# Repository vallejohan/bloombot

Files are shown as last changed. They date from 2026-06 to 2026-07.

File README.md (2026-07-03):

<p align="center">
  
</p>

<h1 align="center">BloomBot</h1>

<p align="center">
  <strong>Your friendly garden irrigation controller.</strong><br>
  Using a Raspberry Pi, with home assistant integration.
</p>

<p align="center">
  <a href="https://github.com/vallejohan/bloombot/actions/workflows/ci.yml">
    
  </a>
  
  <a href="https://github.com/vallejohan/bloombot/blob/main/LICENSE">
    
  </a>
  <a href="https://github.com/vallejohan/bloombot/releases">
    
  </a>
</p>

---

## What is BloomBot?
A lightweight garden and greenhouse irrigation controller running on a **Raspberry Pi Zero W** (or any other Raspberry Pi) to control a 5V relay board. It integrates with **Home Assistant** over **MQTT** using automatic discovery, and supports both scheduled watering (by time-of-day and duration) and manual overrides.

## Features

- **Multi-Channel Relay Control:** Toggle individual water valves/relays on physical GPIO pins.
- **Humidity & temperature measurement:** Measure the humidity and temperature in the garden/greenhouse using an appropriate sensor (such as DHT22 or a DHT11).
- **Home Assistant Auto-Discovery:** No manual YAML configuration required in Home Assistant. Switches, schedule toggles, start times, and watering durations register automatically.
- **Persistent Schedules:** Schedules are stored locally in `schedules.json` so that they survive Raspberry Pi reboots or power cycles.
- **Flexible Timing:** Set the start time (HH:MM:SS) and duration (1 to 10 minutes) for each relay.
- **Safety Auto-Shutoff:** If the scheduler triggers a relay, it automatically shuts off after the configured duration. If a manual OFF override is received during watering, the timer is immediately cancelled.
- **GPIO Fallback & Mocking:** Automatically detects the physical `gpiozero` library. If run on a non-Pi machine (like Windows/Mac for testing), it runs in **Mock mode** allowing you to test Home Assistant communications.

---

## Limitations & Considerations

Before starting there are some limitations with this project that are good to consider: 

- **WiFi Range Outdoors:** The onboard PCB antenna of the Raspberry Pi Zero W has limited range, which is further reduced when placed inside an enclosure. If the Pi is far from your router, you may experience intermittent MQTT disconnections.
   * *Tip:* Consider planning where the hardware should be placed and if any additional WiFi range extenders are needed.
- **Power Consumption:** Unlike low-power microcontrollers (such as the ESP32) which can enter deep-sleep mode and draw microamps, a Raspberry Pi Zero W consumes quite substantially more power.
  * *Tip:* Running BloomBot purely on batteries is doable, but much less efficient compared to for example an ESP32 device. One option could be to use a larger solar panel setup (e.g., 10W+ solar panel, with a larger 12V LiFePO4 battery, and a step-down converter). A mains-powered supply is highly recommended, if possible.
- **No Native Analog Inputs:** The Raspberry Pi lacks analog-to-digital converters (ADC), in case that you'd like to add analog devices. 
   * *Tip:* If you plan to expand the hardware to read analog soil moisture sensors, or utilize other sensors, you will need to add an external ADC device.

> [!NOTE]
> **Design Philosophy & Hardware Selection**
> 
> This project was originally planned around an ESP32 microcontroller. While an ESP32 would be more optimal on several fronts, such as low power consumption, native ADC support, and support for wireless protocols like Zigbee or Thread, a Raspberry Pi was chosen for a few key reasons:
> - **Power & Proximity:** The greenhouse is close to the main house with a direct power line, which minimizes power consumption constraints.
> - **Extensibility & Easy Updates:** Running a full Linux environment allows for trivial Over-the-Air (OTA) updates and leaves the door open to run other companion services on the same device in the future. That being said, there are also options for OTA updates on ESP32 devices as well.
> - **Hardware Reuse:** It was a good opportunity to put a spare Raspberry Pi board I had lying around to good use.

## System Architecture

BloomBot uses a modular architecture to bridge physical hardware with Home Assistant over an MQTT interface. The main components are detailed below, followed by a system diagram showing how they connect.

1. **BloomBot Core (Raspberry Pi):** A Python application running as a system service. It reads ambient temperature and humidity sensors (via a Linux kernel overlay driver) and manages GPIO outputs to trigger relays.
2. **Local Scheduler & Persistence:** The scheduler runs directly on the Pi and relies on a local JSON file (`schedules.json`) for persistence, ensuring that schedules persist and trigger even during network outages.
3. **MQTT Discovery Layer:** On startup, the script registers all switches, sensors, numbers, and system status configuration topics to the Home Assistant MQTT broker automatically.
4. **Home Assistant Control:** A custom companion frontend card (`bloombot-card`) displays status information and allows the user to easily configure watering schedules, durations, and trigger manual overrides.

```mermaid
graph TD
    %% Styling Definitions
    classDef haStyle fill:#03a9f4,stroke:#0288d1,stroke-width:2px,color:#fff;
    classDef mqttStyle fill:#009688,stroke:#00796b,stroke-width:2px,color:#fff;
    classDef rpiStyle fill:#c2185b,stroke:#880e4f,stroke-width:2px,color:#fff;
    classDef hwStyle fill:#4caf50,stroke:#388e3c,stroke-width:2px,color:#fff;
    classDef userStyle fill:#ff9800,stroke:#f57c00,stroke-width:2px,color:#fff;

    %% Nodes
    subgraph HA ["Home Assistant"]
        Card["BloomBot Lovelace Card"]:::haStyle
        HASwitches["Entities (Switches, Sensors, Inputs)"]:::haStyle
    end

    subgraph Broker ["MQTT Broker"]
        MQTT["Mosquitto / MQTT Broker"]:::mqttStyle
    end

    subgraph Pi ["Raspberry Pi Zero W"]
        Core["BloomBot App (main.py)"]:::rpiStyle
        Sched["Scheduler & Persistence (schedules.json)"]:::rpiStyle
        GPIO["GPIO Manager (gpio_manager.py)"]:::rpiStyle
        DHT["DHT Sensor Module (dht_sensor.py)"]:::rpiStyle
    end

    subgraph HW ["Physical Hardware"]
        DHTSensor["DHT22 Sensor"]:::hwStyle
        Relays["8-Channel Relay Board"]:::hwStyle
        Valves["Water Valves / Pumps"]:::hwStyle
    end

    %% Connections
    User["User Interface / App"]:::userStyle --> Card
    Card <-->|Control & Status| HASwitches
    HASwitches <-->|MQTT Pub/Sub| MQTT
    MQTT <-->|Discovery & Commands| Core
    Core <-->|Saves/Reads Schedules| Sched
    Core -->|Triggers Relays| GPIO
    GPIO -->|GPIO Signals| Relays
    Relays -->|Power Control| Valves
    DHTSensor -->|Sensor Data| DHT
    DHT -->|Readings| Core
```

---

## Hardware Setup

To build the BloomBot controller, you will need the hardware components listed in the Bill of Materials section below. The setup is not restricted to the specific models listed, you can choose various components and scale the number of relays (valves) as needed to fit your garden zones.

### Bill of Materials (BOM)

| Component | Description | Quantity | Example | Notes |
| :--- | :--- | :---: | :--- | :--- |
| **Raspberry Pi** | Raspberry Pi Zero W (or Zero 2 W, RPi 3/4/5) with SD Card | 1 | Raspberry Pi Zero 2 W | Any model with a 40-pin GPIO header will work. |
| **Relay Board** | 5V or 3.3V active-low relay module (1 to 8 channels) | 1 | Elegoo 8-Channel Relay Module | Configure the pins in [config.py](src/config.py) based on your board. |
| **DHT22 / DHT11** | Temperature and humidity sensor | 1 | DHT22 (AM2302) | Optional. Used for monitoring climate; can be disabled in configuration. |
| **Water Valves / Pumps** | 12V solenoid valves (or 24V AC valves / 5V DC pumps) | 1 - 8 | Generic 12V Solenoid Valve | Match the quantity to your garden zones and ensure matching power supply. |
| **Power Supplies** | 12V switching PSU & step-down DC-DC converters | 1 - 2 | Meanwell switching 12V PSU & LM2596 Buck Converter | Separate power supply for relay coils is recommended to isolate noise. |
| **Enclosure** | 3D-printable enclosure | 1 | Custom 3D-printed case | Optional. Helps protect components outdoors (see [Enclosure box](#enclosure-box)). |
| **Misc** | Jumper wires, terminal blocks, mounting hardware | - | Dupont jumper wires, Wago 221 connectors | For connecting and mounting the hardware. |

### Wiring

The wiring schematic image below shows how the hardware components can be wired together. Some good points to take into consideration when setting up this system:

- **Active-Low vs. Active-High:** Most common 8-channel relay boards are *Active-Low* (relays switch ON when the control pin is pulled to GND). This is configured via `ACTIVE_LOW = True` in [config.py](src/config.py).
- **Isolating power to relay and Rpi:** To isolate the Raspberry Pi from relay noise and ensure the 5V relay coils have sufficient power, the usage of two 5V DC-DC converters is recommended (as shown in the schematic). However, using a single 5V DC-DC converter is fully functional as well.

<picture>
  BloomBot wiring schematic
</picture>

### Enclosure box

There is an enclosure box that can be 3d-printed to fit the hardware components. The box has holdings for the Raspberry Pi, relay board, and DHT22 sensor, as well as hole for input power and water valve cables. STL files (and 3mf file) can be found in the [assets/3d-models](assets/3d-models) directory.

---

## Installation & Setup on Raspberry Pi

### 1. Install System Dependencies

Open a terminal on your Raspberry Pi and ensure all required system utilities and build tools are installed:

```bash
sudo apt update
sudo apt install -y python3 python3-pip python3-venv python3-gpiozero swig liblgpio-dev python3-dev build-essential
```

> [!NOTE]
> * **Relay Control:** On modern Debian/Ubuntu environments (such as RPi OS Bookworm), legacy GPIO interfaces are deprecated. To control pins correctly, the application compiles `lgpio` in the virtual environment via the modern `/dev/gpiochip*` API, requiring the compilation dependencies (`swig`, `liblgpio-dev`, `python3-dev`, `build-essential`).

### 2. Clone and Prepare the Script

First, install **uv** if it isn't already installed:

```bash
curl -LsSf https://astral.sh/uv/install.sh | sh
```

> [!TIP]
> After the installer completes, you may need to restart your terminal session or run `source $HOME/.local/bin/env` (for bash/zsh) to add `uv` to your `PATH` variable.

Navigate to your workspace directory and synchronize the dependencies to set up a virtual environment:

```bash
cd /path/to/your/workspace/bloombot
uv sync
```

### 3. Enable Linux Kernel DHT Overlay (Required for DHT22 Sensor)

Python-based user-space bit-banging is highly sensitive to CPU scheduling jitter (especially on single-core devices like the Raspberry Pi Zero W). To achieve stable readings, this application relies on the built-in **Linux Kernel Driver**. The kernel handles timing-sensitive pulse measurements asynchronously via hardware interrupts.

To enable the kernel driver:

1. Open the Raspberry Pi firmware configuration file:
   ```bash
   sudo nano /boot/firmware/config.txt
   ```
2. Scroll to the bottom of the file and add the following lines (under the `[all]` block if present):
   ```text
   [all]
   dtoverlay=dht11,dht22,gpiopin=4
   ```
3. Save the file and reboot your Raspberry Pi:
   ```bash
   sudo reboot
   ```

### 4. Configuration

To configure BloomBot, you can copy the `.env.example` template to `.env` and adjust the variables to fit your network and system:

```bash
cp .env.example .env
```

Open `.env` and set the parameters:
- `MQTT_HOST`: Set your Home Assistant broker IP (defaults to `homeassistant.local`).
- `MQTT_PORT`: Port of the broker (defaults to `1883`).
- `MQTT_USERNAME` / `MQTT_PASSWORD`: MQTT broker login credentials if enabled.
- `MQTT_CLIENT_ID`: The client ID for the MQTT connection (defaults to `rpi_relay_controller`).
- `PERSISTENCE_FILE`: File name to save schedules (defaults to `schedules.json`).
- `DHT_PIN`: BCM pin number connected to the DHT sensor (defaults to `4`).
- `DHT_INTERVAL`: Sensor reading and publishing frequency in seconds (defaults to `60`).

*Note: For properties like `ACTIVE_LOW` and `RELAY_PINS`, you can modify their default values directly in [config.py](src/config.py).*

---

## Running the Daemon

### Running Manually (Testing/Development)

You can run the daemon manually to verify the MQTT broker connection and check the terminal log outputs:

```bash
uv run python src/main.py
```

### Running as a Persistent System Service (`systemd`)

To run the daemon automatically when the Pi boots and ensure it restarts on crashes:

1. Create a systemd service file:
   ```bash
   sudo nano /etc/systemd/system/bloombot.service
   ```

2. Paste the following configuration:
   ```ini
   [Unit]
   Description=BloomBot Irrigation Controller Daemon
   After=network.target mqtt.service

   [Service]
   Type=simple
   User=pi
   WorkingDirectory=/home/pi/bloombot
   ExecStart=/home/pi/bloombot/.venv/bin/python src/main.py
   Restart=always
   RestartSec=5

   [Install]
   WantedBy=multi-user.target
   ```

   > [!IMPORTANT]
   > Replace `User=pi`, `/home/pi/` and paths in the service file above with the actual username and directory path of your Raspberry Pi user if your username is not `pi` (modern Raspberry Pi OS installations require a custom username).

   *(Note: The daemon will automatically load the configuration variables from the `.env` file located in the configured `WorkingDirectory`.)*

3. Enable and start the service:
   ```bash
   sudo systemctl daemon-reload
   sudo systemctl enable bloombot.service
   sudo systemctl start bloombot.service
   ```

4. View service logs to monitor execution:
   ```bash
   sudo journalctl -u bloombot.service -f
   ```

---

## Testing in Mock Mode (Without a Raspberry Pi)

If you are developing or testing on a laptop/desktop computer (e.g. Windows/Mac):

1. Synchronize the environment:
   ```bash
   uv sync
   ```
2. Run the application:
   ```bash
   uv run python src/main.py
   ```
3. The daemon will print `[GPIO-MOCK]` lines showing what the physical pins *would* be doing when you toggle switches in Home Assistant.
4. Use **MQTT Explorer** or the Home Assistant developer tools to verify that entities publish their states and commands are received correctly.

---

## Home Assistant Dashboard Setup

This project includes a Lovelace card designed to control scheduled and manual irrigation valves with configuration dialogs.

<p align="center">
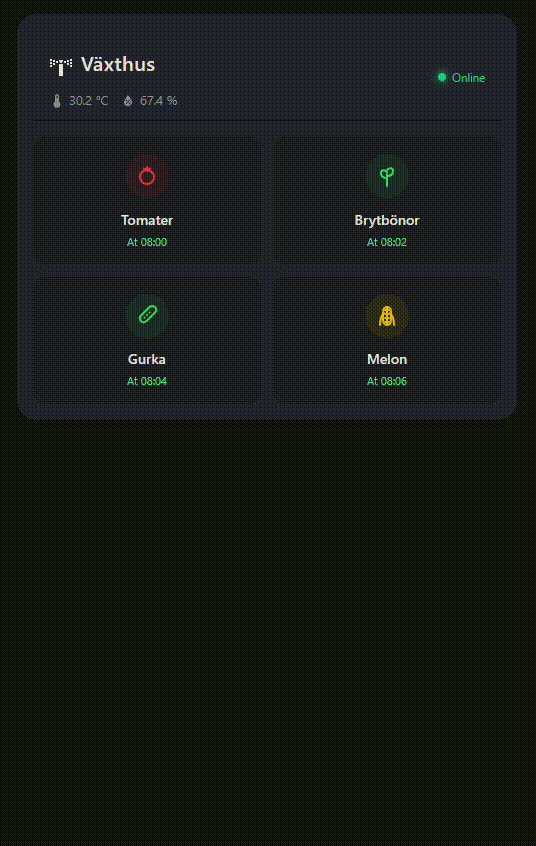
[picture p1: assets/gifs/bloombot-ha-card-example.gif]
BloomBot Home Assistant Card Preview
  
</p>

### New to Home Assistant?

If you do not have a Home Assistant instance running yet, follow these steps to get started:
1. **Installation:** Refer to the official [Home Assistant Installation Guide](https://www.home-assistant.io/installation/) to learn how to install Home Assistant OS or Core on a Raspberry Pi 4/5, dedicated computer, or virtual machine.
2. **HACS Installation:** To install the BloomBot card directly, you need the **Home Assistant Community Store (HACS)**. Follow the official [HACS Download & Setup Guide](https://hacs.xyz/docs/setup/prerequisites) to enable HACS on your instance.

### Installation via HACS (Home Assistant Community Store)

1. Go to **HACS** in your Home Assistant dashboard.
2. Click the **three dots** in the top right corner and select **Custom repositories**.
3. Add the repository URL: `https://github.com/vallejohan/bloombot`
4. Select the category **Dashboard** and click **Add**.
5. The **BloomBot Card** will now appear in your list. Click **Download** in the bottom right corner.

### Dashboard Configuration

Once installed, you can add the card to your dashboard using the Custom UI card selector. 

For the complete configuration options table, list of custom icons, and configuration examples, refer to the [BloomBot card configuration guide (info.md)](info.md).

You can also view a complete dashboard configuration example in [bloombot-card-example.yaml](home-assistant/dashboard-examples/bloombot-card-example.yaml).

---

## Local Unit Testing & Quality Checks

To ensure code health, safety, and format compliance, you can run the following validation tools.

### Python Backend Checks

All Python code quality tools are managed via `uv` in the project's development group.

#### 1. Code Style & Linting (Ruff)
To check for formatting issues and lint warnings:
```bash
uv run ruff check src tests
uv run ruff format --check src tests
```

To automatically format the code and fix auto-fixable lint errors:
```bash
uv run ruff check --fix src tests
uv run ruff format src tests
```

#### 2. Static Type Checks (Mypy)
Verify static types and prevent type errors:
```bash
uv run mypy src tests
```

#### 3. Security Audits (Bandit & Dependency Audit)
Scan for common security vulnerabilities and audit dependencies:
```bash
uv run bandit -r src/
uv audit
```

#### 4. Run the Unit Test Suite
To run the full suite of unit tests:
```bash
uv run python -m unittest discover -s tests
```

---

### BloomBot Home Assistant Card Checks

To run quality checks on the BloomBot Home Assistant card (`dist/bloombot-card.js`), ensure you have Node.js installed, then install the dev dependencies:

```bash
npm install --no-save eslint @eslint/js prettier
```

#### 1. Static Analysis (ESLint)
Verify JavaScript syntax, unresolved variables, and runtime safety:
```bash
npx eslint dist/bloombot-card.js
```

#### 2. Code Formatting (Prettier)
Check and write formatting:
```bash
npx prettier --check dist/bloombot-card.js
npx prettier --write dist/bloombot-card.js
```

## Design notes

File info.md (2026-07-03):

# BloomBot Irrigation Card

A custom gardening card for Home Assistant to control scheduled and manual irrigation valves with configuration dialogs.

BloomBot Home Assistant Card Preview

## Features
- **Vibrant & Responsive Grid Layout**: Card interface designed to control multiple watering zones (relays).
- **Visual Status Indicators**: Instant active/inactive states with color-coded status elements (active/manual/schedule details).
- **Interactive Configuration Modals**: Click on any zone to open a modal dialog allowing you to toggle manual watering, configure scheduling, or adjust watering duration.
- **Embedded Sensors**: Shows current system temperature and humidity metrics if sensors are available.

See [BloomBot GitHub repository](https://github.com/vallejohan/bloombot) for a full walkthrough of the setup.

## Installation

1. Open **HACS** in your Home Assistant dashboard.
2. Search for **BloomBot Card**.
3. Click **Download** in the bottom right corner.

## Dashboard Configuration

Add the card to your dashboard using the Custom UI card selector.

### Configuration Example
```yaml
type: custom:bloombot-card
name: Garden Irrigation
columns: 2
relays:
  - id: 1
    name: Tomatoes
    icon: tomato
    icon_color: "#ef4444"
  - id: 2
    name: Beans
    icon: sprout
    icon_color: "#22c55e"
  - id: 3
    name: Cucumber
    icon: cucumber
    icon_color: "#22c55e"
  - id: 4
    name: Melons
    icon: melon
    icon_color: "#eab308"
```

### Options

| Name | Type | Requirement | Description | Default |
|---|---|---|---|---|
| `type` | string | **Required** | Must be `custom:bloombot-card` (or `custom:bloombot-card-secondary`). | |
| `name` | string | Optional | Header title of the card. | `BloomBot` |
| `columns` | number | Optional | Number of grid columns for the relays list. | `2` |
| `logo_size` | number | Optional | Size of the animated BloomBot logo SVG in pixels. | `44` |
| `show_logo` | boolean | Optional | Enable or disable the animated BloomBot logo SVG header. | `true` |
| `icon` | string | Optional | Material Design Icon to use when `show_logo` is disabled (e.g. `mdi:sprinkler-variant`). | `mdi:sprinkler-variant` |
| `temp_entity` | string | Optional | Temperature sensor entity (e.g., `sensor.bloombot_temperature`). | `sensor.bloombot_temperature` |
| `humidity_entity` | string | Optional | Humidity sensor entity (e.g., `sensor.bloombot_humidity`). | `sensor.bloombot_humidity` |
| `system_status_entity` | string | Optional | System connectivity binary sensor (e.g., `binary_sensor.bloombot_status`). | `binary_sensor.bloombot_status` |
| `relays` | list | **Required** | List of relays to display on the grid. | |

#### Relay Options

| Name | Type | Requirement | Description | Default |
|---|---|---|---|---|
| `id` | number | **Required** | The ID of the relay (1-indexed, e.g. `1` to `8`). | |
| `name` | string | **Required** | Display name for the watering zone. | |
| `entity` | string | Optional | The switch entity to trigger manual watering (e.g., `switch.bloombot_relay_1`). | `switch.bloombot_relay_<id>` |
| `schedule_enabled_entity` | string | Optional | Switch entity to toggle scheduling on/off (e.g., `switch.bloombot_relay_<id>_schedule_enabled`). | `switch.bloombot_relay_<id>_schedule_enabled` |
| `start_times_entity` | string | Optional | Sensor entity containing the schedules array (e.g., `sensor.bloombot_relay_<id>_start_times`). | `sensor.bloombot_relay_<id>_start_times` |
| `duration_entity` | string | Optional | Number input entity for configuring duration in minutes (e.g., `number.bloombot_relay_<id>_duration`). | `number.bloombot_relay_<id>_duration` |
| `icon` | string | Optional | Icon name for the relay (can be a [built-in custom icon name](#built-in-custom-svg-icons) or any standard `mdi:<name>`). | `mdi:water-pump` |
| `icon_color` | string | Optional | CSS color for the active/configured relay icon (e.g., `#ef4444` or `green`). Can also use `color` as an alias. | |

### Built-in Custom SVG Icons

The card includes built-in custom SVG icons for various plants and garden elements. To use one of the custom icons, set the `icon` field of a relay in your dashboard configuration to any of the following names:

* **Vegetables**: `tomato`, `cucumber`, `carrot`, `corn`, `chili`, `pepper`, `pumpkin`, `squash`, `potato`, `eggplant`, `broccoli`, `pea`, `radish`, `cabbage`, `onion`, `garlic`, `mushroom`
* **Fruits**: `apple`, `banana`, `cherry` (or `cherries`), `grape` (or `grapes`), `strawberry`, `pear`, `citrus` (or `orange`, `lemon`), `pineapple`, `watermelon`, `melon`, `berry` (or `berries`)
* **Gardening & Utility**: `sprout`, `leaf`, `flower`, `tree`, `pot`, `sprinkler`, `pump`

*Note: Any other string in the `icon` configuration field will fall back to standard Home Assistant/MDI icons (e.g. `mdi:water`).*

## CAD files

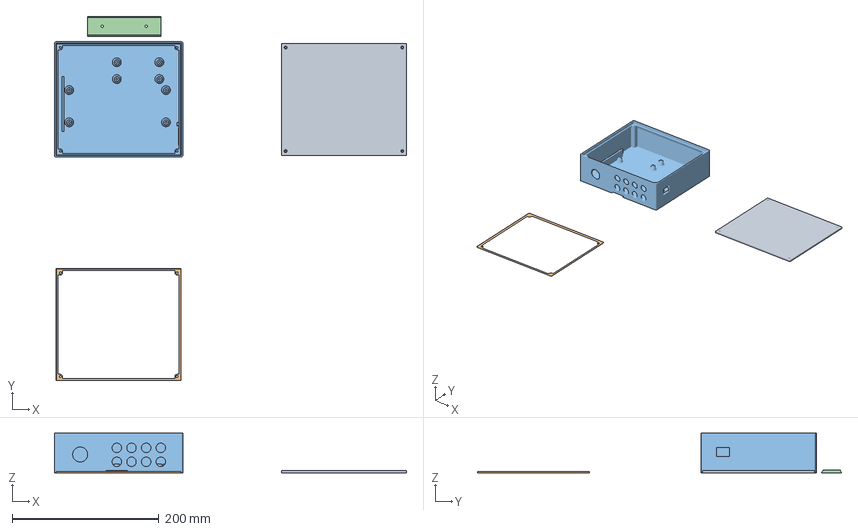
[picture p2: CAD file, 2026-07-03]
assets/3d-models/bloombot.3mf
480.0 x 496.9 x 54.0 mm
floraflow v1.stl_B_B
sealing.stl
box.stl
wall mount.stl

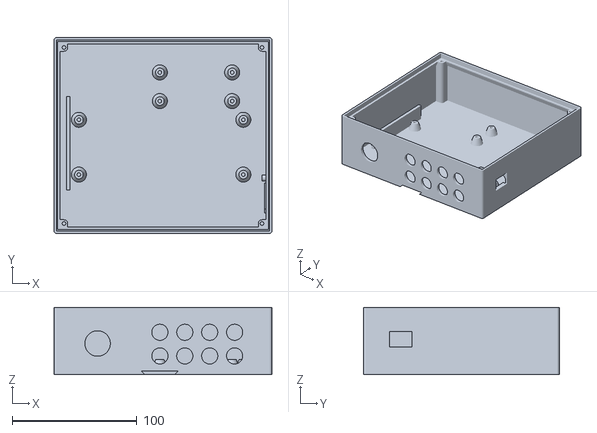
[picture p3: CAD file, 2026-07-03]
assets/3d-models/box.stl
175.0 x 157.2 x 54.0

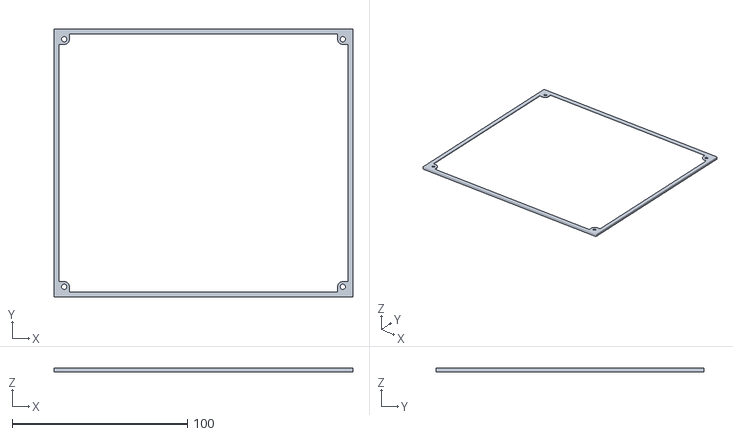
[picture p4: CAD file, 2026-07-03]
assets/3d-models/sealing.stl
170.6 x 152.8 x 2.00

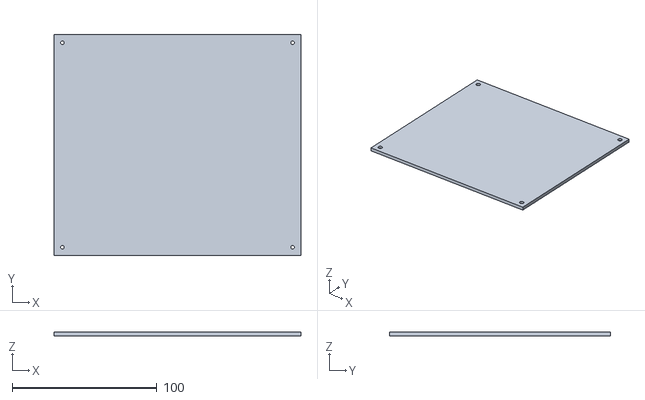
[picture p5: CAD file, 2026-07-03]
assets/3d-models/lid.stl
170.6 x 152.9 x 3.00

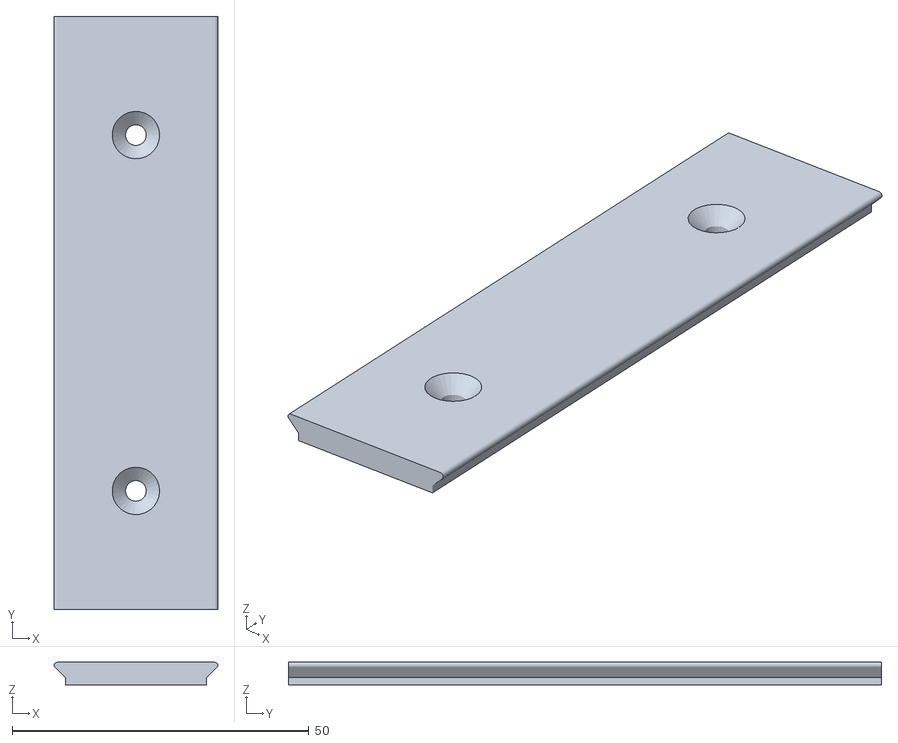
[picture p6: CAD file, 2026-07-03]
assets/3d-models/wall mount.stl
27.6 x 100.0 x 3.80

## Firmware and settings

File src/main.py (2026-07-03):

import json
import logging
import os
import signal
import sys
import time

import config
from dht_sensor import DHTSensorManager
from gpio_manager import GPIOManager
from mqtt_handler import MQTTHandler
from scheduler import GardenScheduler

logging.basicConfig(
    level=logging.INFO,
    format="%(asctime)s [%(levelname)s] %(name)s: %(message)s",
    handlers=[logging.StreamHandler(sys.stdout)],
)
logger = logging.getLogger("Main")


class GardenControllerApp:
    def __init__(self):
        self.schedules = {}
        self.gpio_mgr = None
        self.mqtt_handler = None
        self.scheduler = None
        self.dht_sensor = None
        self.last_dht_read_time = 0
        self.running = False
        self.num_relays = self.count_relays()

        self.load_schedules()

    def count_relays(self):
        if len(config.RELAY_PINS) == 0:
            logger.error("No relay pins configured!")
            sys.exit(1)
        return len(config.RELAY_PINS)

    def load_schedules(self):
        """Load schedules from schedules.json, or initialize with defaults if not found."""
        if os.path.exists(config.PERSISTENCE_FILE):
            try:
                with open(config.PERSISTENCE_FILE, "r") as f:
                    self.schedules = json.load(f)
                logger.info(f"Loaded existing schedules from {config.PERSISTENCE_FILE}")
            except Exception as e:
                logger.error(
                    f"Error loading {config.PERSISTENCE_FILE}: {e}. Initializing defaults."
                )
                self.initialize_default_schedules()
        else:
            logger.info("No schedules file found. Initializing defaults.")
            self.initialize_default_schedules()

        # Ensure all relays exist in schedules
        for i in range(1, self.num_relays + 1):
            key = f"relay_{i}"
            if key not in self.schedules:
                self.schedules[key] = {
                    "schedule_enabled": False,
                    "start_times": [{"time": "08:00:00", "enabled": True}],
                    "duration": 10,
                }
            else:
                sched = self.schedules[key]
                if "start_times" not in sched:
                    sched["start_times"] = [{"time": "08:00:00", "enabled": True}]
        self.save_schedules()

    def initialize_default_schedules(self):
        """Create a default schedule configuration for all relays."""
        self.schedules = {}
        for i in range(1, self.num_relays + 1):
            self.schedules[f"relay_{i}"] = {
                "schedule_enabled": False,
                "start_times": [{"time": "08:00:00", "enabled": True}],
                "duration": 10,
            }

    def save_schedules(self):
        """Write current schedules to schedules.json file."""
        try:
            with open(config.PERSISTENCE_FILE, "w") as f:
                json.dump(self.schedules, f, indent=4)
            logger.debug("Schedules saved to file.")
        except Exception as e:
            logger.error(f"Failed to save schedules: {e}")

    def on_relay_toggle(self, relay_num, state):
        """Callback for manual relay toggle from MQTT."""
        logger.info(
            f"Manual override command received: Relay {relay_num} -> {'ON' if state else 'OFF'}"
        )

        if state:
            self.gpio_mgr.turn_on(relay_num)
        else:
            self.gpio_mgr.turn_off(relay_num)
            self.scheduler.cancel_active_run(relay_num)

        self.mqtt_handler.publish_relay_state(relay_num, state)

    def on_schedule_toggle(self, relay_num, enabled):
        """Callback for schedule enabled state change."""
        key = f"relay_{relay_num}"
        logger.info(
            f"Schedule toggle command received: Relay {relay_num} schedule -> {'ENABLED' if enabled else 'DISABLED'}"
        )

        self.schedules[key]["schedule_enabled"] = enabled
        self.save_schedules()

        self.mqtt_handler.publish_schedule_enabled(relay_num, enabled)

    def on_start_times_change(self, relay_num, payload_str):
        """Callback for schedule start times JSON change."""
        try:
            items = json.loads(payload_str)
            if not isinstance(items, list) or len(items) == 0:
                raise ValueError("Start times must be a non-empty list")

            valid_items = []
            for item in items:
                if not isinstance(item, dict) or "time" not in item:
                    continue
                time_str = item["time"].strip()
                # Validate format (expect HH:MM or HH:MM:SS)
                parts = time_str.split(":")
                if len(parts) in (2, 3):
                    h = int(parts[0])
                    m = int(parts[1])
                    if 0 <= h < 24 and 0 <= m < 60:
                        if len(parts) == 2:
                            time_str = f"{h:02d}:{m:02d}:00"
                        enabled = bool(item.get("enabled", False))
                        valid_items.append({"time": time_str, "enabled": enabled})

            if len(valid_items) == 0:
                raise ValueError("No valid start times provided")

            key = f"relay_{relay_num}"
            logger.info(
                f"Schedule start times change: Relay {relay_num} -> {valid_items}"
            )
            self.schedules[key]["start_times"] = valid_items
            self.save_schedules()

            self.mqtt_handler.publish_start_times(relay_num, valid_items)

        except Exception as e:
            logger.error(
                f"Invalid start times payload received for relay {relay_num}: {payload_str}. Error: {e}"
            )
            key = f"relay_{relay_num}"
            self.mqtt_handler.publish_start_times(
                relay_num, self.schedules[key]["start_times"]
            )

    def on_duration_change(self, relay_num, duration):
        """Callback for schedule watering duration change."""
        key = f"relay_{relay_num}"
        duration = max(1, min(10, duration))
        logger.info(
            f"Schedule duration change: Relay {relay_num} -> {duration} minutes"
        )

        self.schedules[key]["duration"] = duration
        self.save_schedules()

        self.mqtt_handler.publish_duration(relay_num, duration)

    def toggle_relay_from_scheduler(self, relay_num, state, is_scheduled=True):
        """Callback invoked by the scheduler when it starts or stops watering."""
        logger.info(
            f"[SCHEDULER ACTION] Relay {relay_num} -> {'ON' if state else 'OFF'}"
        )

        if state:
            self.gpio_mgr.turn_on(relay_num)
        else:
            self.gpio_mgr.turn_off(relay_num)

        self.mqtt_handler.publish_relay_state(relay_num, state)

    def publish_initial_states(self):
        """Publish current system configurations and relay states to Home Assistant."""
        logger.info("Synchronizing initial state with Home Assistant...")
        for i in range(1, self.num_relays + 1):
            key = f"relay_{i}"
            sched = self.schedules[key]

            # Initial relay state is OFF when daemon starts
            self.mqtt_handler.publish_relay_state(i, False)
            self.mqtt_handler.publish_schedule_enabled(i, sched["schedule_enabled"])
            self.mqtt_handler.publish_start_times(i, sched["start_times"])
            self.mqtt_handler.publish_duration(i, sched["duration"])

    def run(self):
        self.running = True

        self.gpio_mgr = GPIOManager(config.RELAY_PINS, config.ACTIVE_LOW)

        self.scheduler = GardenScheduler(
            self.schedules, self.toggle_relay_from_scheduler
        )
        self.scheduler.start()

        if config.DHT_ENABLED:
            self.dht_sensor = DHTSensorManager(config.DHT_PIN)

        self.mqtt_handler = MQTTHandler(
            on_relay_toggle=self.on_relay_toggle,
            on_schedule_toggle=self.on_schedule_toggle,
            on_start_times_change=self.on_start_times_change,
            on_duration_change=self.on_duration_change,
        )
        self.mqtt_handler.connect()

        try:
            time.sleep(2.0)
            self.publish_initial_states()

            logger.info("Relay Controller Daemon is running. Press Ctrl+C to exit.")
            last_heartbeat_time = 0.0
            while self.running:
                now = time.time()

                if now - last_heartbeat_time >= config.HEARTBEAT_INTERVAL:
                    self.mqtt_handler.publish_heartbeat()
                    last_heartbeat_time = now

                if now - self.last_dht_read_time >= config.DHT_INTERVAL:
                    self.read_and_publish_dht()
                    self.last_dht_read_time = now

                time.sleep(1)
        except KeyboardInterrupt:
            logger.info("KeyboardInterrupt received, stopping...")
        finally:
            self.shutdown()

    def read_and_publish_dht(self):
        """Reads temperature and humidity from the DHT22 sensor and publishes to Home Assistant."""
        if self.dht_sensor:
            logger.info("Reading DHT22 sensor data...")
            temp, hum = self.dht_sensor.read()
            if temp is not None or hum is not None:
                self.mqtt_handler.publish_sensor_data(temp, hum)
            else:
                logger.warning("Failed to read data from DHT22 sensor")

    def shutdown(self):
        logger.info("Shutting down cleanly...")
        self.running = False

        if self.scheduler:
            self.scheduler.stop()

        if self.mqtt_handler:
            self.mqtt_handler.disconnect()

        if self.gpio_mgr:
            logger.info("Turning off all relays for safety.")
            for i in range(1, self.num_relays + 1):
                try:
                    self.gpio_mgr.turn_off(i)
                except Exception:  # nosec B110
                    pass
            self.gpio_mgr.cleanup()

        logger.info("Shutdown complete.")


def main():
    app = GardenControllerApp()

    def signal_handler(signum, frame):
        logger.info(f"Received system signal {signum}")
        app.running = False

    signal.signal(signal.SIGINT, signal_handler)
    signal.signal(signal.SIGTERM, signal_handler)

    app.run()


if __name__ == "__main__":
    main()

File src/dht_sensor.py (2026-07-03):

import glob
import logging
import os
import random
import time

logger = logging.getLogger(__name__)


class DHTSensorManager:
    """Manages reading from a physical DHT22 sensor via the Linux kernel IIO driver, falling back to mock values."""

    def __init__(self, pin: int):
        self.pin = pin
        self.is_mock = False
        self.iio_path = None
        self.last_valid_temp = None
        self.last_valid_hum = None

        try:
            iio_devices = glob.glob("/sys/bus/iio/devices/iio:device*")
            for dev_path in iio_devices:
                temp_file = os.path.join(dev_path, "in_temp_input")
                hum_file = os.path.join(dev_path, "in_humidityrelative_input")
                if os.path.exists(temp_file) and os.path.exists(hum_file):
                    self.iio_path = dev_path
                    logger.info(f"Using Linux Kernel IIO driver at {self.iio_path}")
                    break
        except Exception as e:
            logger.debug(f"Failed to search for kernel IIO driver paths: {e}")

        if not self.iio_path:
            logger.warning(
                "Linux Kernel IIO driver not found. Falling back to simulated/MOCK DHT22."
            )
            self.is_mock = True

    def read(self):
        """Reads temperature and humidity. Returns (temperature, humidity) tuple or (None, None) on failure."""
        if self.is_mock:
            temp = round(random.uniform(19.0, 23.0), 1)  # nosec B311
            humidity = round(random.uniform(50.0, 60.0), 1)  # nosec B311
            logger.debug(f"[DHT-MOCK] Read temperature={temp}°C, humidity={humidity}%")
            return temp, humidity

        # Read via Linux Kernel IIO Driver
        if self.iio_path:
            for attempt in range(1, 4):
                try:
                    temp_file = os.path.join(self.iio_path, "in_temp_input")
                    hum_file = os.path.join(self.iio_path, "in_humidityrelative_input")

                    with open(temp_file, "r") as f:
                        temp = float(f.read().strip()) / 1000.0
                    with open(hum_file, "r") as f:
                        humidity = float(f.read().strip()) / 1000.0

                    temp_c = round(temp, 1)
                    humidity_pct = round(humidity, 1)

                    if not (-40.0 <= temp_c <= 80.0 and 0.0 <= humidity_pct <= 100.0):
                        logger.warning(
                            f"Discarding out-of-bounds sensor reading (attempt {attempt}/3): temp={temp_c}°C, hum={humidity_pct}%"
                        )
                        if attempt < 3:
                            time.sleep(1.0)
                        continue

                    if self.last_valid_temp is not None:
                        if abs(temp_c - self.last_valid_temp) > 10.0:
                            logger.warning(
                                f"Discarding temperature spike (attempt {attempt}/3): {temp_c}°C (previous: {self.last_valid_temp}°C)"
                            )
                            if attempt < 3:
                                time.sleep(1.0)
                            continue

                    if self.last_valid_hum is not None:
                        if abs(humidity_pct - self.last_valid_hum) > 30.0:
                            logger.warning(
                                f"Discarding humidity spike (attempt {attempt}/3): {humidity_pct}% (previous: {self.last_valid_hum}%)"
                            )
                            if attempt < 3:
                                time.sleep(1.0)
                            continue

                    self.last_valid_temp = temp_c
                    self.last_valid_hum = humidity_pct
                    return temp_c, humidity_pct
                except Exception as e:
                    logger.warning(
                        f"Error reading from Linux Kernel IIO driver (attempt {attempt}/3): {e}"
                    )
                    if attempt < 3:
                        time.sleep(1.0)
            return None, None

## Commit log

2026-06-16 bugfix: resolve issue with non-functioning adafruit_dht library to read DHT22 (#1)
    Migrate to using Linux kernel IIO driver to read the temperature and humidity of the DHT22 sensor, which has shown more reliable readings. Update the readme with instructions on how to set it up as well.
    [dht_sensor.py]
2026-06-25 feat: update pin configuration for relays (#2)
    This change aims to make the wiring a bit easier, since the GPIO pins on the Raspberry Pi Zero aren't numbered incrementally.
2026-06-28 feat: add ability to add/remove start times for each relay, remove migration logic (#3)
    * feat: add ability to add/remove start times for each relay, instead of having just one start time for each
    * feat: remove migration logic for start_time, update comment
    * feat: resolve format issues
    [main.py, mqtt_handler.py, scheduler.py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]
2026-06-30 feat: update readme, remove redundant comments, update schedule duration logic (#5)
    * doc: revise README file, remove redundant comments in the codebase
    * feat: update time constraint for watering duration, update affected test cases
    * feat: add kicad project for wiring schematic
    [floraflow.kicad_sch]
2026-06-30 feat: add DHT_ENABLED flag to allow disabling the sensor if not used, add test cases for it (#6)
2026-07-03 feat: extend icons in ha card, update documentation, add 3d models (#7)
    * feat: extend list of available icons for vegetables and fruits, add node check for HA card in ci.yaml
    * feat: add 3d files for enclosure box, fix formatting, minor documentation updates
    [box.stl, floraflow.3mf, lid.stl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]
2026-07-03 Feature/rename project (#8)
    - **Branding Rename:** Renamed all directories, files, 3D models, HACS manifests, workflow configs, Python files (config.py), and Lovelace custom card registration from FloraFlow to BloomBot.
    - **Animated Logo SVG:** Added a custom animated vector logo featuring a floating squircle-head robot with blinking eyes holding a swaying flower (bloombot-logo.svg).
    - **Active Watering State:** Configured the card to dynamically toggle a raining animation on the bloombot logo in the card when any zone is active.
    - **Polished Rain Speed:** Tuned rain droplet speed (~0.8s cycle) and fall distance (160px coordinate space) to run smoothly and fall all the way off-screen.
    - **Up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
    [bloombot.3mf, bloombot.kicad_sch, floraflow.3mf]
2026-07-03 fix: add gpiozero to dependencies (#9)
    This resolves an issue where gpiozero was not in the uv environment, making the code to falling back to using mock class when controlling relays.
2026-07-03 Feature/extend ci tasks (#10)
    * feat: add new testing steps in ci action, also update existing
    Replace black/isort with Ruff for linting and formatting. Add Mypy for static type checking and Bandit for security audits. Also add ESLint and Prettier for the Home Assistant card. Expand CI matrix to test Python 3.9-3.12 instead of just 3.10. Add branch/path filtering to workflow triggers. Update documentation to reflect new tools and their usage. Format the Home Assistant card for consistency.
    * feat: dummy update
    * fix: resolve ruff formatting
    * fix: remove unused variable and ignore line-length linting
    * fix: add bandit security suppressions
    Add nosec comments to suppress bandit warnings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
    [dht_sensor.py, main.py, mqtt_handler.py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]

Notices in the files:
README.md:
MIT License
